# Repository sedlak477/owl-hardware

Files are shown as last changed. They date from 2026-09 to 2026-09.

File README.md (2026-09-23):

# OWL Hardware

Hardware design files for the OWL measurement tool.

<p align="center">
  Exploded 3D render
</p>

The OWL is a rotating platform driven by a BLDC motor under field-oriented control.
Power and USB data are passed from the stationary base to the rotating part through a slip ring,
so devices mounted on top can be rotated continuously while staying connected to a host.

## Status

- **[v1.0.0](https://github.com/sedlak477/owl-hardware/releases/tag/v1.0.0)** is the OWL as built and tested. It works, with the known issues listed in its release notes:
  the 5V rail can oscillate when USB and the power supply are both connected (workaround: cut the controller's `VBUS` jumper JP1),
  the stator's data USB-C port only works in one cable orientation,
  the sensor's mounting holes are missing (drill them, 1.8 mm),
  the green LEDs are very bright,
  and the USB hub (IC1) has no pin-1 marker.
- **Releases after v1.0.0**, including the latest, should fix these issues, but no boards have been built from them yet, so they are **untested**.
  Other changes since the built boards: plated shell-tab holes for the controller's USB-C connector J3, a different part for the controller's `USER` LED D7, and no assembled parts on the controller's bottom side.
- The 5V oscillation is only worked around: JP1 now ships open, so the controller runs from the power supply only (see [Power supply](docs/Assembly%20instructions.md#power-supply)). A proper fix is planned for the next board revision.

## Building an OWL

1. Download the files from the [latest release](https://github.com/sedlak477/owl-hardware/releases/latest):
   - `owl-<version>-jlcpcb.zip`: everything needed to order the three assembled PCBs from JLCPCB
   - `owl-<version>-3d-print.zip`: the 3D-printed parts
   - `owl-<version>-generic.zip`: manufacturer-neutral PCB files and schematics, if you order elsewhere
2. Order the PCBs, see [pcb/README.md](pcb/README.md).
3. Print the parts, see [cad/README.md](cad/README.md).
4. Assemble the OWL and flash the firmware, see the [assembly instructions](docs/Assembly%20instructions.md).
5. Print an adapter for your payload, see [payload/README.md](payload/README.md).

## Architecture

Hardware architecture

- **Stator PCB**: Sits in the stationary base. Provides the USB-C power input with a USB PD trigger (CH224K) and the USB data port to the host.
- **Rotor PCB** (controller): Rotates with the platform. Contains the RP2354B controller, the DRV8311 BLDC driver, 5 V and 3.3 V regulators, a USB hub with a passthrough port for the payload, and a Qwiic (I²C) port.
- **Magnetic sensor PCB**: Measures the rotor angle for motor control using a magnetic angle sensor.

## Repository structure

| Path | Content |
| :--- | :--- |
| `pcb/controller` | KiCad project for the rotor/controller PCB. |
| `pcb/stator` | KiCad project for the stator PCB. |
| `pcb/sensor` | KiCad projects for the magnetic sensor PCBs. |
| `cad` | Link to the Onshape document and 3D-print files.|
| `payload` | Adapters for mounting payloads, and the payload interface. |
| `docs` | Assembly instructions, renders, and diagrams. |

Each PCB folder contains a `schematic.pdf`, the KiCad project in `src`, and production files in `production` (generic, and ready to upload to JLCPCB). See [pcb/README.md](pcb/README.md) for the stackups and how to order the boards.

## Editing the design

Requirements:

- [KiCad](https://www.kicad.org/) 10 or newer
- [Git LFS](https://git-lfs.com/) for STEP models, PDFs, images, and fabrication archives

```sh
git lfs install
git clone git@github.com:sedlak477/owl-hardware.git
```

After changing a board, regenerate its production files with `pcb/export-production.sh` (see [pcb/README.md](pcb/README.md#regenerating-the-production-files-only-after-changing-the-design)).
Pushing a tag starting with `v` (e.g. `v1.1.0`) creates a release with the packaged production and 3D-print files.

## Related resources

[owl-firmware](https://github.com/sedlak477/owl-firmware): The firmware for the OWL platform.  
[owl-ranger](https://github.com/sedlak477/owl-ranger): A script for stepping through some orientations and recording measurements.  
[pyowl](https://github.com/sedlak477/pyowl): A python library for interacting with the OWL.  
[Dataset](https://doi.org/10.3217/kh254-z8374): Orientation-diverse BLE Channel Sounding and UWB ranging measurements recorded with the OWL.

## License

Copyright 2026 Michael Sedlak. Licensed under [CERN-OHL-P-2.0](LICENSE), without any warranty.

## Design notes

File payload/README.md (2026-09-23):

# Payloads

A payload is the device you rotate with the OWL, such as a development board or a set of motion-capture markers.
It sits on an adapter, which locks into the payload connector on top of the OWL (`Rotor - Payload Connector` in [`cad/`](../cad/README.md)).

To attach an adapter, put its pegs through the holes in the payload connector and twist it to lock it in place.
Twist it back to take it off.

> [!CAUTION]
> The pegs are fragile. Don't force the adapter when you twist it.

## Folder structure

| Path | Content |
| :--- | :--- |
| `generic/` | The generic adapter: a blank plate with the pegs, to extend for your own payload. |
| `adapters/<name>/` | Ready-made adapters, each with a STEP model, an image and a README. |
| `mounts/<name>/` | Mounts that provide a payload connector without an OWL. |

## Adapters

| Adapter | For |
| :--- | :--- |
| [`nrf52840dk`](adapters/nrf52840dk/README.md) | Nordic nRF52840 DK |
| [`nrf54l15dk`](adapters/nrf54l15dk/README.md) | Nordic nRF54L15 DK |
| [`dwm3001cdk`](adapters/dwm3001cdk/README.md) | Qorvo DWM3001CDK |
| [`mocap`](adapters/mocap/README.md) | Five optical motion-capture markers |
| [`quarter-inch-thread`](adapters/quarter-inch-thread/README.md) | Anything with a camera tripod screw (female 1/4"-20 thread) |
| [`zip-tie-ring`](adapters/zip-tie-ring/README.md) | Anything you can fix with zip ties or straps |

These adapters were made for our own experiments, and some of them are quick designs that could be done better.
If you improve one, please contribute it back (see [Contributing](#contributing)).

## Using adapters without an OWL

The [tripod mount](mounts/tripod/README.md) screws onto a camera tripod and has the same payload connector as the OWL, so every adapter fits it.
Use it for devices that stay fixed in your setup, such as anchors or reference nodes: they sit on the same adapters and at the same geometry as the rotating ones, and you can move a device between an OWL and a fixed position without taking it off its adapter.

## Electrical interface

The controller PCB on the rotating part offers two connectors for the payload.

### USB-C passthrough

The main connection for a payload.
This port is a downstream port of the controller's USB 2.0 hub, so a payload plugged in there shows up on the host next to the OWL itself, over the same data cable through the slip ring.
It also powers the payload from the controller's 5V rail. With the controller's `VBUS` solder jumper open (as manufactured), that rail runs from the power supply, so the payload is only powered while the power supply is connected.

### Qwiic / STEMMA QT

A JST SH 4-pin connector with the Qwiic / STEMMA QT pinout:

| Pin | Signal | RP2354B |
| :-- | :----- | :--- |
| 1 | GND | |
| 2 | 3.3V | |
| 3 | SDA | GPIO0 |
| 4 | SCL | GPIO1 |

This port connects to the OWL's controller, not to the host, so using it requires changes to the [firmware](https://github.com/sedlak477/owl-firmware).
The controller has no pull-up resistors on SDA and SCL; most Qwiic / STEMMA QT modules have their own.
GPIO0 and GPIO1 can also be configured as UART0 TX and RX, so the port can be used as a UART port instead.

## Designing your own adapter

Start from the generic adapter and build your holder on top of the plate, leaving the pegs unchanged so it still locks into the payload connector.
It is in the [Onshape document](https://cad.onshape.com/documents/fccfa08dfedefe67cfdb683e/w/4726c041ddb97f340fe57a69/e/d62cb220f0c6f90c2b79ed01) with the rest of the OWL, where you can copy it, and in [`generic/payload-generic.step`](generic/payload-generic.step) for any other CAD tool.

## Contributing

New adapters and mounts are welcome, and so are improvements to the existing ones. Add a folder `adapters/<name>/` (or `mounts/<name>/`) with a short lowercase name without spaces, for example the board it holds, containing:

- `<name>.step`: the model
- `<name>.png`: an image of it
- `README.md`: what it holds and any extra hardware needed (screws, inserts, glue)
- optionally `<name>.3mf`, ready to slice

Then add it to the table above and open a pull request.
Contributions are licensed under the same [CERN-OHL-P-2.0](../LICENSE) as the rest of the OWL hardware.

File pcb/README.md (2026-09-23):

# PCBs

| Board | Folder | Layers | Size | Thickness | Copper | Solder mask | Parts on |
| :--- | :--- | :----- | :--- | :--- | :--- | :--- | :--- |
| Rotor / controller | `controller/` | 4 | 60 x 60 mm | 1.6 mm | 1 oz outer, 0.5 oz inner  | Purple | top only |
| Stator | `stator/` | 2 | 44 x 44 mm | 1.6 mm | 1 oz | Black | both sides  |
| Magnetic sensor (MA600A) | `sensor/ma600a/` | 2 | 22.3 x 20 mm | 1.6 mm | 1 oz | Yellow | both sides  |

ENIG surface finish is recommended.
Minimum track width and clearance are 0.15 mm, minimum drill is 0.25 mm (controller) or 0.3 mm (stator, sensor).

Each board folder contains:

| Path | Content |
| :--- | :--- |
| `schematic.pdf` | Schematic. |
| `src/` | KiCad project and STEP model of the assembled board. |
| `production/generic/` | Files for any manufacturer (see below). |
| `production/jlcpcb/`  | Files ready to upload to JLCPCB for fabrication and assembly. |

The easiest way to get the files is the [latest release](https://github.com/sedlak477/owl-hardware/releases/latest): `owl-<version>-jlcpcb.zip` has the JLCPCB files and `owl-<version>-generic.zip` the generic files and schematics, each with one folder per board.

## Ordering from JLCPCB

> [!WARNING]
> **Check the rotation of every part in JLCPCB's placement preview before you order.**
> JLCPCB's part models don't always line up with the footprints, so some parts can show up rotated (often by 90° or 180°) or shifted.
> JLCPCB assembles the board as the preview shows it: a wrongly rotated IC, LED or connector is soldered on the wrong way round, and the board has to be reworked or thrown away.
> See step 5 below.

Order each board (`controller`, `stator`, `sensor-ma600a`) separately. Download and unzip `owl-<version>-jlcpcb.zip`, then for each board:

1. Go to [jlcpcb.com](https://jlcpcb.com), click *Order now*, and upload `<board>/<board>-gerbers.zip`. Don't unzip it, JLCPCB wants the zip.
2. Check that layers, size and thickness match the table above, and pick the solder mask color you like.
3. Enable *PCB Assembly*. The controller is assembled on the top side only; the stator and the sensor have parts on both sides, so select assembly on both sides for them.
4. Upload `<board>/<board>-bom.csv` as the BOM and `<board>/<board>-positions.csv` as the CPL (pick-and-place) file.
5. Check the part matching, then go through **every part** in the placement preview and check both its position and its rotation:
   - Position: its pins sit on their pads.
   - Rotation of ICs: the pin-1 marker on the part (dot, notch or bevel) sits at the pin-1 marker on the silkscreen.
   - Rotation of LEDs: the cathode sits at the cathode marker on the silkscreen.
   - Rotation of connectors: the part matches its silkscreen outline, with the opening on the correct side.

   Rotate or move any part that is off directly in the preview before ordering. Resistors and ceramic capacitors are not polarized, so for them a 180° rotation does not matter.

On the controller, the optional RM2 radio module (U6) and microSD socket (J8) are marked DNP and are not assembled, and neither are their support parts on the bottom side (C43, C44, R1, R2). Solder them by hand if you need them; their values and part numbers are in the schematic.

## Ordering elsewhere

`owl-<version>-generic.zip` (or `production/generic/` in each board folder) contains manufacturer-neutral files, plus each board's schematic:

| File | Content |
| :--- | :--- |
| `<board>-gerbers.zip` | Gerber X2 layers, Excellon drill files (plated and non-plated separate), and a Gerber job file with the stackup. |
| `<board>-netlist.ipc` | IPC-D-356 netlist for electrical testing. |
| `<board>-bom.csv` | BOM with manufacturer and manufacturer part number (MPN), plus the LCSC number where available. |
| `<board>-positions.csv` | Pick-and-place file as exported by KiCad (mm, rotation in KiCad convention, both sides). |

The Gerbers work at any PCB manufacturer.
Assembly houses usually want the BOM and position files in their own format; the columns in the generic files map directly to theirs.
Rotation conventions differ between assembly houses, so **check the rotation of every polarized part in their placement preview**, the same way as for JLCPCB (step 5 above).
The JLCPCB position file is not generic: it contains JLCPCB-specific rotation and offset corrections.

## Regenerating the production files (only after changing the design)

Not needed for ordering boards: the production files in each release are ready to use.

Run `pcb/export-production.sh` (or `pcb/export-production.sh <board>` for one board: `controller`, `stator`, `sensor-ma600a`).
It needs `kicad-cli` (KiCad 10) and, for the JLCPCB files, the [Fabrication Toolkit](https://github.com/bennymeg/Fabrication-Toolkit) KiCad plugin.
Set `KICAD_PYTHON` to the Python interpreter KiCad uses if it is not the default `python3`, and `FABRICATION_TOOLKIT_DIR` if the plugin is not installed in `~/.local/share/kicad/10.0/3rdparty/plugins`.

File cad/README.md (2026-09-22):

# CAD

The mechanical parts of the OWL are designed in Onshape:

<https://cad.onshape.com/documents/fccfa08dfedefe67cfdb683e/w/4726c041ddb97f340fe57a69/e/d62cb220f0c6f90c2b79ed01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>

The Onshape document is the source of truth. Anything in this folder is an export of it.

## Printing the parts

Download `owl-<version>-3d-print.zip` from the [latest release](https://github.com/sedlak477/owl-hardware/releases/latest) and print **`OWL.3mf`**.
It contains all parts for one OWL, already laid out on one plate with a brim, so you only have to open it in your slicer, pick your printer and filament, and print.
Use a heat-resistant filament like ABS or ASA: the motor gets warm, and the motor adapter and the parts around it must not soften.

Alternatively, the archive has one STEP file per part, for example to arrange the parts yourself or to print only the motor adapter in ABS and the rest in another material.

## Files

The same files are in [`3d-print/`](3d-print/):

| File | Content |
| :--- | :--- |
| `OWL.3mf` | All parts for one OWL, laid out on a plate, ready to slice. |
| `Stator - Motor Adapter.step` | Motor adapter. Print in a heat-resistant filament (e.g. ABS). |
| `Stator - Small Spacer.step` | Small spacers between motor adapter and stator PCB. |
| `Stator - Big Spacer.step` | Big spacers between stator PCB and tripod adapter. |
| `Stator - Tripod Adapter.step` | Tripod adapter with the 1/4'' heat insert. |
| `Rotor - Board Spacers.step` | Spacers between sensor PCB and controller PCB. |
| `Rotor - Payload Connector.step` | Payload connector on top of the rotor. |

Each STEP file contains as many copies of the part as one OWL needs.

See the [assembly instructions](../docs/Assembly%20instructions.md) for how the parts go together.

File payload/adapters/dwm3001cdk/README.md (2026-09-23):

# DWM3001CDK adapter

Holds a Qorvo [DWM3001CDK](https://www.qorvo.com/products/p/DWM3001CDK) upright on the OWL. The board snaps into the clips, no screws needed.

DWM3001CDK adapter

| File | Content |
| :--- | :--- |
| `dwm3001cdk.step` | STEP model of the adapter. |

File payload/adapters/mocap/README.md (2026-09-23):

# Motion-capture marker adapter

Carries five optical motion-capture markers on arms of different lengths, so the motion-capture system can track the OWL's rotation as a rigid body.
The arrangement is asymmetric, so every orientation is unambiguous.

Glue the markers onto the round pads at the ends of the arms.

Motion-capture marker adapter

| File | Content |
| :--- | :--- |
| `mocap.step` | STEP model of the adapter. |

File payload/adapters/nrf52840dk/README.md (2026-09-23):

# nRF52840 DK adapter

Holds a Nordic [nRF52840 DK](https://www.nordicsemi.com/Products/Development-hardware/nRF52840-DK) upright on the OWL.

Fix the DK to the plate with M2.5 screws. Nylon screws are recommended.

nRF52840 DK adapter

| File | Content |
| :--- | :--- |
| `nrf52840dk.step` | STEP model of the adapter. |

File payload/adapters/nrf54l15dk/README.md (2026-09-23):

# nRF54L15 DK adapter

Holds a Nordic [nRF54L15 DK](https://www.nordicsemi.com/Products/Development-hardware/nRF54L15-DK) upright on the OWL.

Fix the DK to the plate with M2.5 screws. Nylon screws are recommended.

nRF54L15 DK adapter

| File | Content |
| :--- | :--- |
| `nrf54l15dk.step` | STEP model of the adapter. |

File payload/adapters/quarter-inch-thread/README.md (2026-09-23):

# 1/4" thread adapter

Gives the OWL a female 1/4"-20 UNC thread, the same as on the bottom of a camera.
Anything made for a camera tripod screw can be mounted on it.

To mount a payload that itself has a 1/4" tripod hole, screw a 1/4"-20 male-to-male stud (sold as a "1/4" to 1/4" screw adapter") into this adapter.

It uses the same 1/4" heat insert as the OWL's tripod adapter (see the [assembly instructions](../../../docs/Assembly%20instructions.md)).

1/4 inch thread adapter

| File | Content |
| :--- | :--- |
| `quarter-inch-thread.step` | STEP model of the adapter. |

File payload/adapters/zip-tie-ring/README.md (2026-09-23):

# Zip-tie ring

A plain ring with openings, for fixing payloads that have no dedicated adapter with zip ties, hook-and-loop straps or similar.

Zip-tie ring

| File | Content |
| :--- | :--- |
| `zip-tie-ring.step` | STEP model of the adapter. |

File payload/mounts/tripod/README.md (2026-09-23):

# Tripod mount

Screws onto a camera tripod and provides the same payload connector as the OWL, so any adapter snaps into it just like into an OWL.
Use it for devices that stay fixed in a setup, such as anchors or reference nodes, with the same adapters and mounting geometry as the rotating ones.

It uses the same 1/4" heat insert as the OWL's tripod adapter (see the [assembly instructions](../../../docs/Assembly%20instructions.md)).

Tripod mount

| File | Content |
| :--- | :--- |
| `tripod.step` | STEP model of the mount. |

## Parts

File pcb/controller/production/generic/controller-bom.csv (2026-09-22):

Designator | Quantity | Value | Footprint | Manufacturer | MPN | LCSC
C1,C31,C32,C33 | 4 | 10u 50V | Capacitor_SMD:C_0805_2012Metric | Murata | GRM21BR61H106KE43L | C440198
C2,C14 | 2 | 4.7u | Capacitor_SMD:C_0402_1005Metric | Samsung Electro-Mechanics | CL05A475MP5NRNC | C23733
C3,C10,C11 | 3 | 10u | Capacitor_SMD:C_0603_1608Metric | Samsung Electro-Mechanics | CL10A106KP8NNNC | C19702
C4,C6,C34 | 3 | 100n 50V | Capacitor_SMD:C_0402_1005Metric | Samsung Electro-Mechanics | CL05B104KB54PNC | C307331
C5,C7 | 2 | 4.7u | RP2350_80QFN_minimal:C_0402_1005Metric_small_pads | Samsung Electro-Mechanics | CL05A475MP5NRNC | C23733
C8,C9,C12,C13,C15,C16,C17,C18,C21,C23,C25,C26,C27,C28,C29,C30,C38 | 17 | 100n | Capacitor_SMD:C_0402_1005Metric | Samsung Electro-Mechanics | CL05B104KO5NNNC | C1525
C19,C20 | 2 | 15p | Capacitor_SMD:C_0402_1005Metric | Fenghua | 0402CG150J500NT | C1548
C22,C24 | 2 | 1u | Capacitor_SMD:C_0402_1005Metric | Samsung Electro-Mechanics | CL05A105KA5NQNC | C52923
C35,C36,C37 | 3 | 22u | Capacitor_SMD:C_0603_1608Metric | Fenghua | 0603X226M100NT | C60077
C39,C40 | 2 | 18p | Capacitor_SMD:C_0402_1005Metric | Fenghua | 0402CG180J500NT | C1549
C42 | 1 | 100n 50V | Capacitor_SMD:C_0402_1005Metric | Murata | GRM155R71H104KE14D | C77020
D2,D8,D9 | 3 | KT-0805G | LED_SMD:LED_0805_2012Metric | Hubei KENTO Elec | KT-0805G | C2297
D4 | 1 | KT-0805Y | LED_SMD:LED_0805_2012Metric | Hubei KENTO Elec | KT-0805Y | C2296
D5,D6 | 2 | KT-0805R | LED_SMD:LED_0805_2012Metric | NATIONSTAR | NCD0805R1 | C84256
D7 | 1 | KT-0805B | LED_SMD:LED_0805_2012Metric | Hubei KENTO Elec | KT-0805B | C2293
IC1 | 1 | USB2422-I_MJ | USB2422-I_MJ:QFN50P400X400X100-25N | Microchip | USB2422-I/MJ | C220747
J1 | 1 | Motor | Connector_Molex:Molex_PicoBlade_53261-0371_1x03-1MP_P1.25mm_Horizontal | Molex | 532610371 | C293630
J3 | 1 | USB_C_Receptacle_USB2.0_14P | Connector_USB:USB_C_Receptacle_GCT_USB4105-xx-A_16P_TopMnt_Horizontal | Global Connector Technology | USB4105-GF-A-060 | C3025063
J4 | 1 | Slip Ring | JST PA 6P:CONN_BM06B-PASS-1_JST | JST | BM06B-PASS-TFT(LF)(SN) | C265376
J5 | 1 | 781715006 | Molex Pico-EZmate 781715006:CONN06_781715006_MOL | Molex | 781715006 | C107412
J6 | 1 | SM03B-SRSS-TB | Connector_JST:JST_SH_SM03B-SRSS-TB_1x03-1MP_P1.00mm_Horizontal | JST | SM03B-SRSS-TB(LF)(SN) | C160403
J9 | 1 | SM04B-SRSS-TB_LF__SN_ | SM04B-SRSS-TB:JST_SM04B-SRSS-TB_LF__SN_ | JST | SM04B-SRSS-TB(LF)(SN) | C160404
L1 | 1 | 3.3u | AOTA-B201610S3R3-101-T:AOTAB201610S3R3101T | Abracon | AOTA-B201610S3R3-101-T | C42411119
PS1 | 1 | TPSM84338RCJR | TPSM84338RCJR:CONV_TPSM84338RCJR | Texas Instruments | TPSM84338RCJR | C47122151
R3,R6 | 2 | 1.43k | Resistor_SMD:R_0402_1005Metric | Yageo | RC0402FR-071K43L | C163483
R4 | 1 | 10k | Resistor_SMD:R_0402_1005Metric | UNI-ROYAL | 0402WGF1002TCE | C25744
R5,R22,R23,R24,R26 | 5 | 47k | Resistor_SMD:R_0402_1005Metric | UNI-ROYAL | 0402WGF4702TCE | C25792
R11 | 1 | 270 | Resistor_SMD:R_0402_1005Metric | Yageo | RC0402FR-07270RL | C163474
R13 | 1 | 33 | Resistor_SMD:R_0402_1005Metric | UNI-ROYAL | 0402WGF330JTCE | C25105
R14,R15,R18,R34,R36,R41 | 6 | 1k | Resistor_SMD:R_0402_1005Metric | UNI-ROYAL | 0402WGF1001TCE | C11702
R16,R17 | 2 | 27 | Resistor_SMD:R_0402_1005Metric | Yageo | RC0402FR-0727RL | C138021
R19,R20 | 2 | 100k | Resistor_SMD:R_0402_1005Metric | UNI-ROYAL | 0402WGF1003TCE | C25741
R21 | 1 | 12k | Resistor_SMD:R_0402_1005Metric | UNI-ROYAL | 0402WGF1202TCE | C25752
R25,R27 | 2 | 22k | Resistor_SMD:R_0402_1005Metric | UNI-ROYAL | 0402WGF2202TCE | C25768
R28 | 1 | 330 | Resistor_SMD:R_0402_1005Metric | UNI-ROYAL | 0402WGF3300TCE | C25104
R29 | 1 | 110k | Resistor_SMD:R_0402_1005Metric | Yageo | RC0402FR-07110KL | C138065
R30 | 1 | 15k | Resistor_SMD:R_0402_1005Metric | UNI-ROYAL | 0402WGF1502TCE | C25756
R31 | 1 | 0 | Resistor_SMD:R_0402_1005Metric | UNI-ROYAL | 0402WGF0000TCE | C17168
R32 | 1 | 18k | Resistor_SMD:R_0402_1005Metric | UNI-ROYAL | 0402WGF1802TCE | C25762
R38,R40 | 2 | 360 | Resistor_SMD:R_0402_1005Metric | FOJAN | FRC0402F3600TS | C2930003
R39 | 1 | 4.7k | Resistor_SMD:R_0402_1005Metric | UNI-ROYAL | 0402WGF4701TCE | C25900
SW1 | 1 | BOOTSEL | Button_Switch_SMD:SW_SPST_B3U-1000P | G-Switch | GT-TC032A-H015-L1 | C843684
SW2 | 1 | RESET | Button_Switch_SMD:SW_SPST_B3U-1000P | G-Switch | GT-TC032A-H015-L1 | C843684
SW3 | 1 | USER | Button_Switch_SMD:SW_SPST_B3U-1000P | G-Switch | GT-TC032A-H015-L1 | C843684
U1 | 1 | AP2112K-3.3 | Package_TO_SOT_SMD:SOT-23-5 | TECH PUBLIC | AP2112K-3.3TRG1 | C23380830
U2 | 1 | LM66200DRLR | LM66200DRLR:SOT-5X3_DRL_TEX | Texas Instruments | LM66200DRLR | C3235556
U3 | 1 | PDRV8311HRRWR | DRV8311:RRW0024-MFG | Texas Instruments | DRV8311HRRWR | C5218862
U4 | 1 | RP2354B | Package_DFN_QFN:QFN-80-1EP_10x10mm_P0.4mm_EP3.4x3.4mm_ThermalVias | Raspberry Pi | RP2354B | C39843328
U5 | 1 | USBLC6-2P6 | Package_TO_SOT_SMD:SOT-666 | TECH PUBLIC | USBLC6-2P6 | C2827693
Y1 | 1 | ABM8-272-T3 | ABM8-272-T3:XTAL_ABM8-272-T3 | Abracon | ABM8-272-T3 | C20625731
Y2 | 1 | 7M-24.000MAAJ-T | 7M-24.000MAAJ-T:7M24000MAAJT | TXC | 7M-24.000MAAJ-T | C2450233

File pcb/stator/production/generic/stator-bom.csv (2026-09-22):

Designator | Quantity | Value | Footprint | Manufacturer | MPN | LCSC
C1,C4 | 2 | 100n | Capacitor_SMD:C_0402_1005Metric | Fenghua | 0402F104M500NT | C1581
C3 | 1 | 1u | Capacitor_SMD:C_0402_1005Metric | Samsung Electro-Mechanics | CL05A105KA5NQNC | C52923
J1 | 1 | DATA | Connector_USB:USB_C_Receptacle_GCT_USB4110 | Global Connector Technology | USB4110-GF-A | C5143397
J2 | 1 | SLIP RING | JST PA 6P SMT:CONN_BM06B-PASS-1_JST | JST | BM06B-PASS-TFT(LF)(SN) | C265376
J3 | 1 | POWER | Connector_USB:USB_C_Receptacle_GCT_USB4110 | Global Connector Technology | USB4110-GF-A | C5143397
R1,R6 | 2 | 330 | Resistor_SMD:R_0402_1005Metric | UNI-ROYAL | 0402WGF3300TCE | C25104
R2,R3 | 2 | 5.1k | Resistor_SMD:R_0402_1005Metric | UNI-ROYAL | 0402WGF5101TCE | C25905
R4,R7,R8,R9 | 4 | 10k | Resistor_SMD:R_0402_1005Metric | UNI-ROYAL | 0402WGF1002TCE | C25744
R5 | 1 | 1k | Resistor_SMD:R_0805_2012Metric | UNI-ROYAL | AS05W2J0102T5E | C560481
U2 | 1 | CH224K | Package_SO:SSOP-10-1EP_3.9x4.9mm_P1mm_EP2.1x3.3mm | WCH | CH224K | C970725

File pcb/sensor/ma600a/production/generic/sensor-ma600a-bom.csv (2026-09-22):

Designator | Quantity | Value | Footprint | Manufacturer | MPN | LCSC
C1 | 1 | 100n | Capacitor_SMD:C_0603_1608Metric | Yageo | CC0603KRX7R9BB104 | C14663
C2 | 1 | 1u | Capacitor_SMD:C_0603_1608Metric | Samsung Electro-Mechanics | CL10A105KB8NNNC | C15849
J1 | 1 | 781715006 | Molex Pico-EZmate 781715006:CONN06_781715006_MOL | Molex | 781715006 | C107412
U2 | 1 | MA600A | Package_DFN_QFN:QFN-16-1EP_3x3mm_P0.5mm_EP1.75x1.75mm | Monolithic Power Systems | MA600AGQE-0000-Z | C49240579

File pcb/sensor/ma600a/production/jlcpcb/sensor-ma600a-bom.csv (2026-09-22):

Designator | Footprint | Quantity | Value | LCSC Part #
C1 | 0603 | 1 | 100n | C14663
C2 | 0603 | 1 | 1u | C15849
J1 | CONN06_781715006_MOL | 1 | 781715006 | C107412
U2 | QFN-16-1EP_3x3mm_P0.5mm_EP1.75x1.75mm | 1 | MA600A | C49240579

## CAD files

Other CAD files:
cad/3d-print/OWL.3mf
payload/adapters/dwm3001cdk/dwm3001cdk.step
payload/adapters/mocap/mocap.step
payload/adapters/nrf54l15dk/nrf54l15dk.step
payload/adapters/quarter-inch-thread/quarter-inch-thread.step
payload/adapters/zip-tie-ring/zip-tie-ring.step
payload/generic/payload-generic.step
payload/mounts/tripod/tripod.step
pcb/controller/src/OWL - Rotor v2.step
pcb/sensor/ma600a/src/Sensor - MA600A.step
pcb/stator/src/Stator.step
cad/3d-print/Rotor - Payload Connector.step
cad/3d-print/Rotor - Board Spacers.step
cad/3d-print/Stator - Small Spacer.step
cad/3d-print/Stator - Big Spacer.step
cad/3d-print/Stator - Motor Adapter.step
cad/3d-print/Stator - Tripod Adapter.step
payload/adapters/nrf52840dk/nrf52840dk.step

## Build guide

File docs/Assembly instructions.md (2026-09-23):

1. 3D-print all parts & cleanup from print (especially the payload connector mounting holes). Download `owl-<version>-3d-print.zip` from the [latest release](https://github.com/sedlak477/owl-hardware/releases/latest) and print `OWL.3mf`: it has all parts for one OWL laid out on one plate, ready to slice. Print it in a heat-resistant filament like ABS or ASA, because the motor gets warm and the motor adapter and the parts around it must not soften. If you want to arrange the parts yourself, or print only some of them in another material, use the STEP files in the same archive instead (see [`cad/`](../cad/README.md)).
2. Prepare materials
	1. 1x BLDC motor: SparkFun [ROB-20441](https://www.sparkfun.com/three-phase-brushless-gimbal-stabilizer-motor.html) (Mouser 474-ROB-20441)
	2. 1x slip ring, 6 wire, 2A: SparkFun [ROB-13064](https://www.sparkfun.com/slip-ring-6-wire-2a.html) (Mouser 474-ROB-13064)
	3. 1x stator PCB, 1x controller PCB, 1x sensor PCB, ordered assembled from JLCPCB with the files in `owl-<version>-jlcpcb.zip` from the [latest release](https://github.com/sedlak477/owl-hardware/releases/latest); see [how to order the boards](../pcb/README.md)
	4. 3x M5 nuts
	5. 3x M5 counter-sunk screws, 40mm long
	6. 3x M1.6x6 flat-head screws
	7. 3x M1.6x10 flat-head screws
	8. 1x 1/4'' heat insert, 8.7mm outer diameter, ~12.7mm long (a shorter one works too, it just must not be longer)
	9. 1x Molex Pico-EZmate cable assembly, 6 circuits, 50mm: [36920-0600](https://www.molex.com/en-us/products/part-detail/369200600) (Mouser 538-36920-0600)
	10. 2x JST PA 6-pin housing (PAP-06V-S) with 12x crimp contacts, for the slip ring
	11. 2x USB-C cables. Take care with cheap cables: many are charge-only and have no data lines.
	12. 1x USB-C power supply that can deliver the voltage the stator requests (see below)
3. Tools: soldering iron (for the heat insert), crimping tool for JST PA contacts, wire strippers, side cutters, 2mm allen key, multimeter
4. Break the PCBs out of their panels, if they came panelized: snap or cut off the panel rails and file the leftover breakaway tabs flush.
5. Press the 1/4'' heat insert into the tripod adapter
	1. Insert until 1mm still sticks out
	2. While still hot, turn around and press against flat surface (CAUTION: Don't press on the center with your finger or you could burn yourself on the heat insert)
	3. This ensures the insert is level with the bottom surface
6. Put the M5 bolts into the motor adapter
7. Mount the motor to the top of the motor adapter
	1. Pre-screw the M1.6x6 screws into the small holes; Leave 1/2mm sticking out of the top to make aligning the motor easier
	2. Ensure the M5 bolts are already inserted into the big holes
	3. Align the motor (magnetic ring facing away) with the screws and tighten the screws
	4. Ensure the motor does not wiggle and it rotates freely. If it sounds like it is scraping, then the screws are going in too far and are damaging the motors internals!

	Motor mounted on the motor adapter with the three M5 bolts inserted

8. Thread the cables of the slip ring through the motor and slide it onto the M5 screws. The thin side of the slip ring should disappear into the motor adapter and the flange should sit flush against the motor adapter.

	Slip ring cables being threaded through the motor and motor adapter

9. Add one small spacer to each M5 screw, then slide on the stator PCB with the connectors facing *away* from the assembly. Ensure you thread the slip ring cables through the large center hole of the stator PCB and the connectors are aligned with the symbols (the JST connector should be on the side where there's no symbol)

	Stator PCB slid onto the M5 bolts over the small spacers, slip ring cables through the center hole

10. Cut the cables to size (leave some slack to allow for some mistakes when crimping), strip the ends, and crimp on the JST crimps.
11. Insert the crimps into the connector housing, remember the order (or better, take a picture). The order does not matter, but it just has to match the order on the other side. I recommend ordering them so the cables can lie pretty coming out of the connector.

	Crimped slip ring wires in the JST PA housing, in the order yellow, red, black, green, orange, brown

	Slip ring wires crimped and inserted into the housing, plugged into the stator PCB

12. Insert the connector
13. Slide two big spacers onto each M5 screw, carefully bend the cables to the side, and slide on the tripod adapter.

	Big spacers on the M5 bolts with the slip ring cables bent to the side

14. Screw the M5 nuts onto the ends of the M5 screws. Depending on 3D printing tolerances, an allen key should just fit beside the motor to turn the screw. After a few rotations, the nut will be held in place by the tripod adapter and you can tighten it all the way.

	Finished stator assembly with the tripod adapter, M5 nuts and heat insert

15. The stator assembly is now finished!
16. Thread the slip ring and motor cables through the center hole of the controller PCB and place it on top of the motor.

	Controller PCB placed on top of the motor with the slip ring and motor cables through its center hole

17. Again, cut the wires to length and crimp on the connector (same as steps 10 & 11). Ensure you insert the cables in the same order as on the other end.
18. Before plugging anything in, check the slip ring wiring with a multimeter. Unplug the housing on the stator side and measure continuity between the two housings: pin 1 must reach pin 1, pin 2 must reach pin 2, and so on. If the crimps went in mirrored, the order still "matches" but VM ends up on VBUS. Also check that no two neighbouring pins are shorted by a crimp.
19. Plug in the slip ring connector and the motor connector.
20. !!!!! Make sure the slip ring cables are bent to the side and lay flat against the PCB, so the sensor can later be mounted on top.
21. Plug the Pico-EZmate cable into the sensor PCB. Lay the sensor flat on the table, align the connector from the top and just press down, the connector should click into place very easily.
22. Thread the M1.6x10 screws through the payload connector, slide on the sensor PCB (the sensor IC facing *away* from the payload connector), and slide on the board spacers. The fit on the spacers is tight, so I recommend screwing into them and letting 2mm stick out for alignment.

	Payload connector with the sensor PCB and board spacers, side view Payload connector with the sensor PCB and board spacers, top view

23. Align the controller PCB with the motor's mounting holes, add the payload connector + sensor assembly on top, and screw the three M1.6 screws down into the motor.
24. Plug the other end of the Pico-EZmate cable into the controller PCB.

## Power supply

The stator uses a CH224K USB PD trigger to ask the power supply for the motor voltage.
Which voltage it requests is set by the solder jumpers JP1 (CFG1), JP2 (CFG2) and JP3 (CFG3) on the stator PCB.
As manufactured, the stator requests 9V.
Any USB-C PD supply that offers 9V will do.

You can change the requested voltage with the jumpers.
If you do, also set `SUPPLY_VOLTAGE` in the firmware's [`src/main.cpp`](https://github.com/sedlak477/owl-firmware/blob/main/src/main.cpp) to the new voltage, otherwise SimpleFOC computes the wrong phase voltages.
The firmware limits the motor to 4V (`motor.voltage_limit`); keep it below the motor's 7.4V rating.

The controller's 5V rail comes from its regulator, which runs from the motor supply.
It can also be powered from USB through the `VBUS` solder jumper JP1 on the controller PCB, which is open as manufactured.
Bridge JP1 only if the controller should also run from USB power alone: with both power and data connected, the controller's power path can then keep switching between the two sources and make the 5V rail noisy.

## Checks

You are now done with the mechanical assembly! A few checks before continuing:
- Make sure the top rotates freely
- Check the following LEDs
	- Power plugged in, data **unplugged**
		- `VM`: green
		- `5V`: green
		- `3.3V`: green
		- Rest off (`USB`, `USER`, `DRV FAULT`, `PG`)
	- Power **unplugged**, data plugged in
		- All off, since the controller only runs from the power supply (JP1 open)
		- If you bridged JP1: `5V` green, `3.3V` green, `USB` yellow, rest off (`VM`, `USER`, `DRV FAULT`, `PG`)
	- Both plugged in
		- `VM`: green
		- `5V`: green
		- `3.3V`: green
		- `USB`: yellow
		- Rest off  (`USER`, `DRV FAULT`, `PG`)

If those checks passed, you can continue on to flashing the firmware.

## Flashing the firmware

1. Download the latest `.uf2` image from the [owl-firmware releases](https://github.com/sedlak477/owl-firmware/releases) page.
2. Plug in the data cable and the power cable. On a new board the flash is blank, so the controller starts in BOOT mode by itself.
3. To reflash a board that already has firmware, put it into BOOT mode: hold the BOOT button, press and release RESET, then release BOOT. Holding BOOT while plugging in the power cable works too.
4. The OWL will show up as a USB thumb drive.
5. Copy the firmware image to this drive.
6. The controller will flash the firmware and reset.
7. Done!

## First power-up and the 0° position

Every time the controller starts (power-up, reset, or right after flashing), the firmware:

1. Calibrates the motor against the sensor: the top twitches briefly back and forth.
2. Slowly turns the top to its 0° position. This can take up to almost one full revolution.

Keep the top free to rotate while this happens: if it is blocked, the calibration fails.
You can tell the two cases apart by hand:

- **Calibrated:** the top resists when you push it and always returns to its set point.
- **Calibration failed:** the motor is switched off and the top turns freely by hand. Power-cycle the OWL to try again.

The 0° position comes from the magnetic sensor, so it is the same physical orientation every time the OWL starts, as long as it is not taken apart.
It is not tied to any mark on the OWL and differs from one OWL to the next.
To get a known orientation in your test setup, power the OWL up, wait until it has turned to 0°, and then turn the whole OWL (for example on its tripod) until the payload faces your reference direction.
Pressing the `USER` button also sends the OWL back to 0° (one second after you release it).

The controller and sensor PCBs both have a `0°` silkscreen mark. You don't need to line them up: the firmware does not use them. Defining a mechanical zero with these marks is future work.

## What next

To mount your device on the OWL, print an adapter for it, see [`payload/`](../payload/README.md).
For a first controlled move, use [pyowl](https://github.com/sedlak477/pyowl), the Python library for the OWL.
To step through orientations and record measurements, use [owl-ranger](https://github.com/sedlak477/owl-ranger).

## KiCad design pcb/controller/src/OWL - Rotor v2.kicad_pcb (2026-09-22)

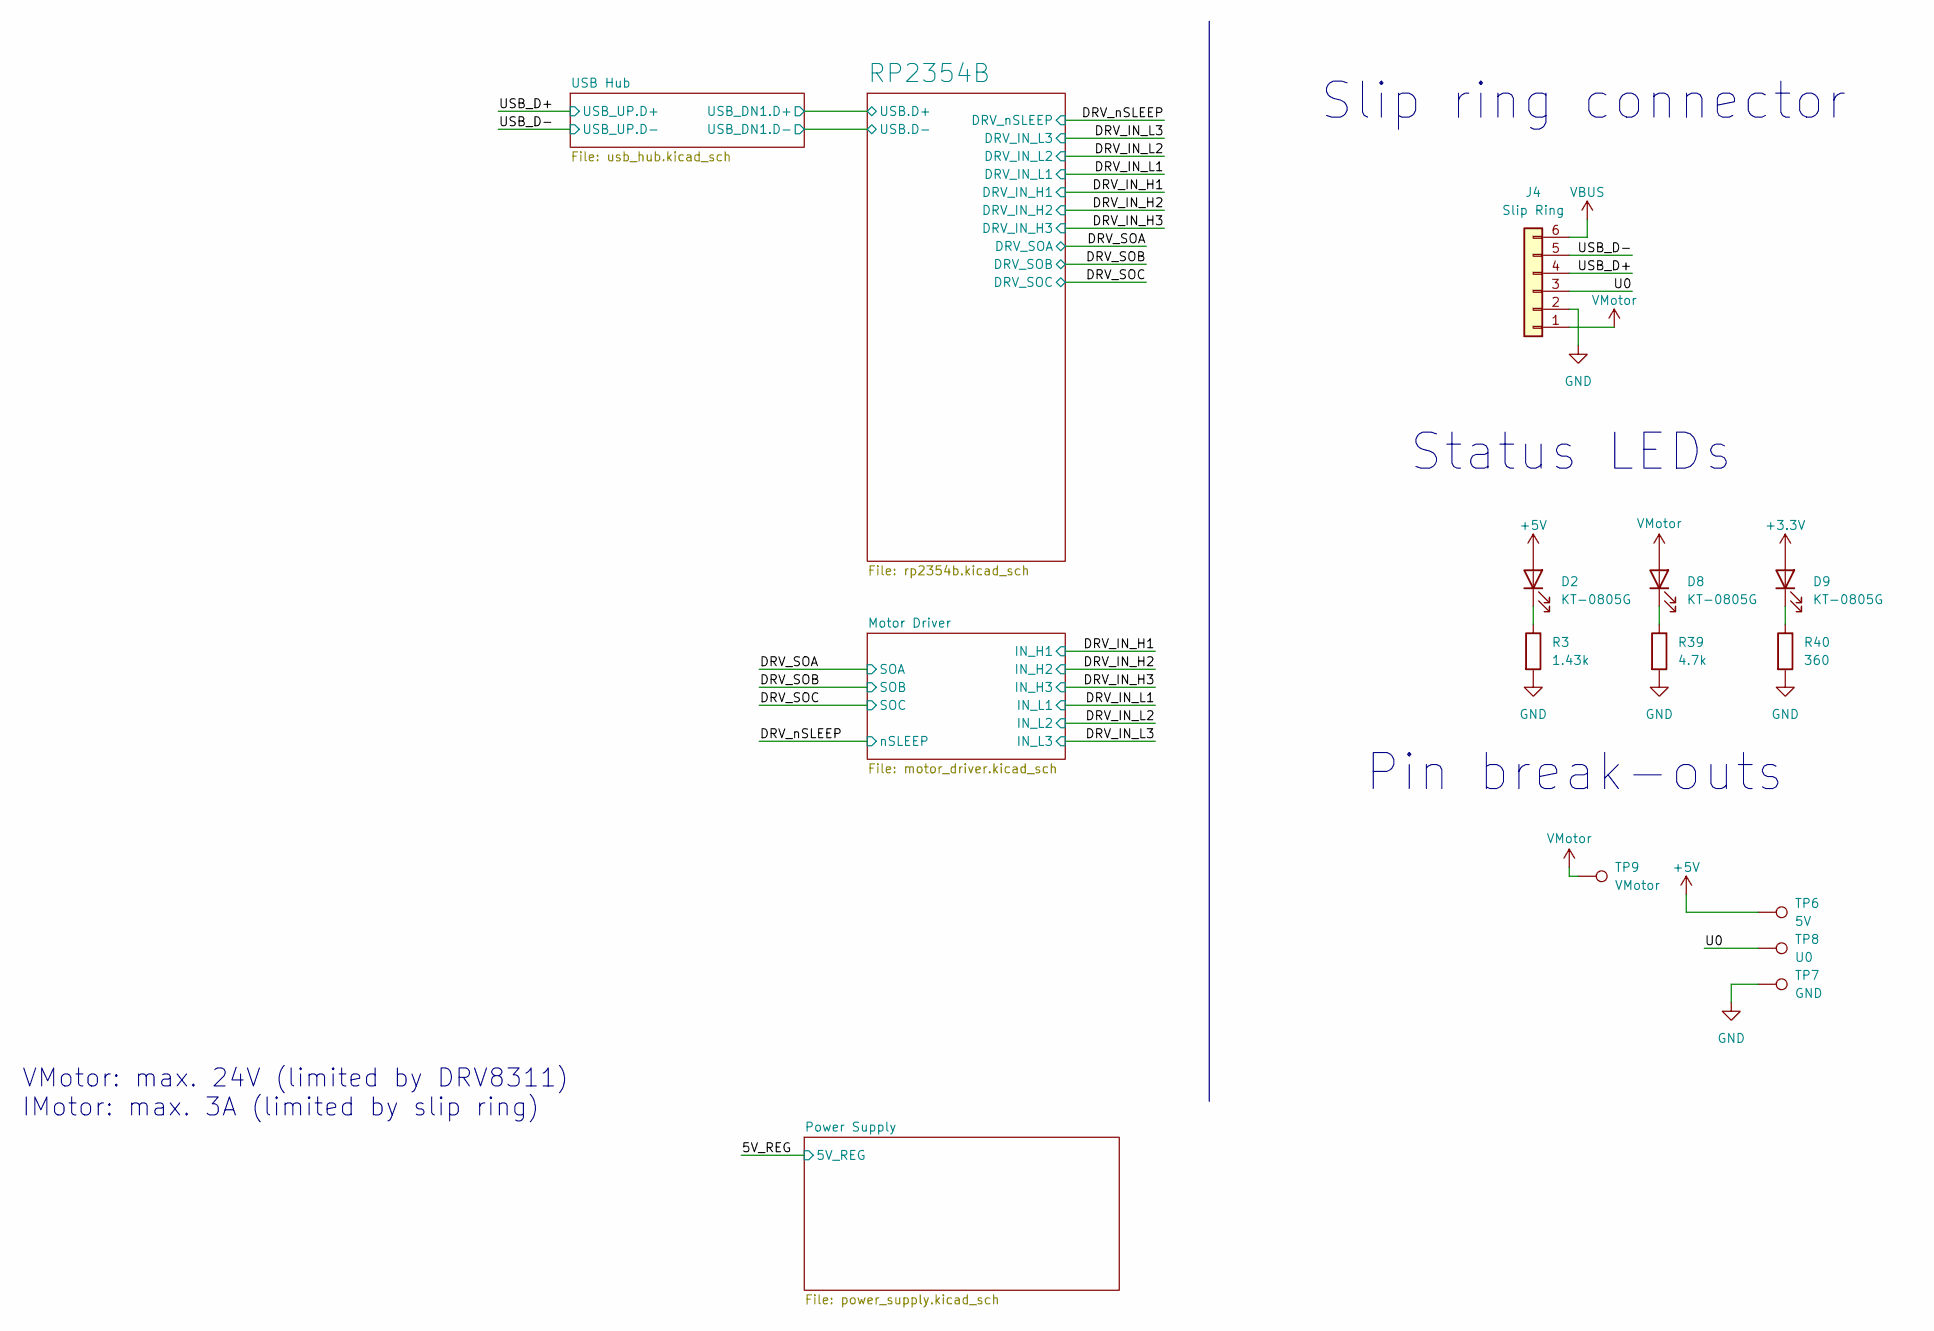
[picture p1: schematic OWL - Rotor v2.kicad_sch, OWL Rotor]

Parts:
D2, D8, D9: KT-0805G; LED_0805_2012Metric; MPN KT-0805G; LCSC C2297
J4: Slip Ring; CONN_BM06B-PASS-1_JST; MPN BM06B-PASS-TFT(LF)(SN); LCSC C265376
R3: 1.43k; R_0402_1005Metric; MPN RC0402FR-071K43L; LCSC C163483
R39: 4.7k; R_0402_1005Metric; MPN 0402WGF4701TCE; LCSC C25900
R40: 360; R_0402_1005Metric; MPN FRC0402F3600TS; LCSC C2930003
TP6: 5V; TestPoint_Pad_D1.0mm
TP7: GND; TestPoint_Pad_D1.0mm
TP8: U0; TestPoint_Pad_D1.0mm
TP9: VMotor; TestPoint_Pad_D1.0mm

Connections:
+3.3V: D9.2 (A); also elsewhere on the board
+5V: D2.2 (A), TP6.1; also elsewhere on the board
/U0: J4.3, TP8.1
/USB_D+: J4.4; also elsewhere on the board
/USB_D-: J4.5; also elsewhere on the board
GND: J4.2, R3.2, R39.2, R40.2, TP7.1; also elsewhere on the board
unnamed: D2.1 (K), R3.1
unnamed: D8.1 (K), R39.1
unnamed: D9.1 (K), R40.1
VBUS: J4.6; also elsewhere on the board
VMotor: D8.2 (A), J4.1, TP9.1; also elsewhere on the board

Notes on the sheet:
VMotor: max. 24V (limited by DRV8311) IMotor: max. 3A (limited by slip ring)
Status LEDs
Slip ring connector
Pin break-outs

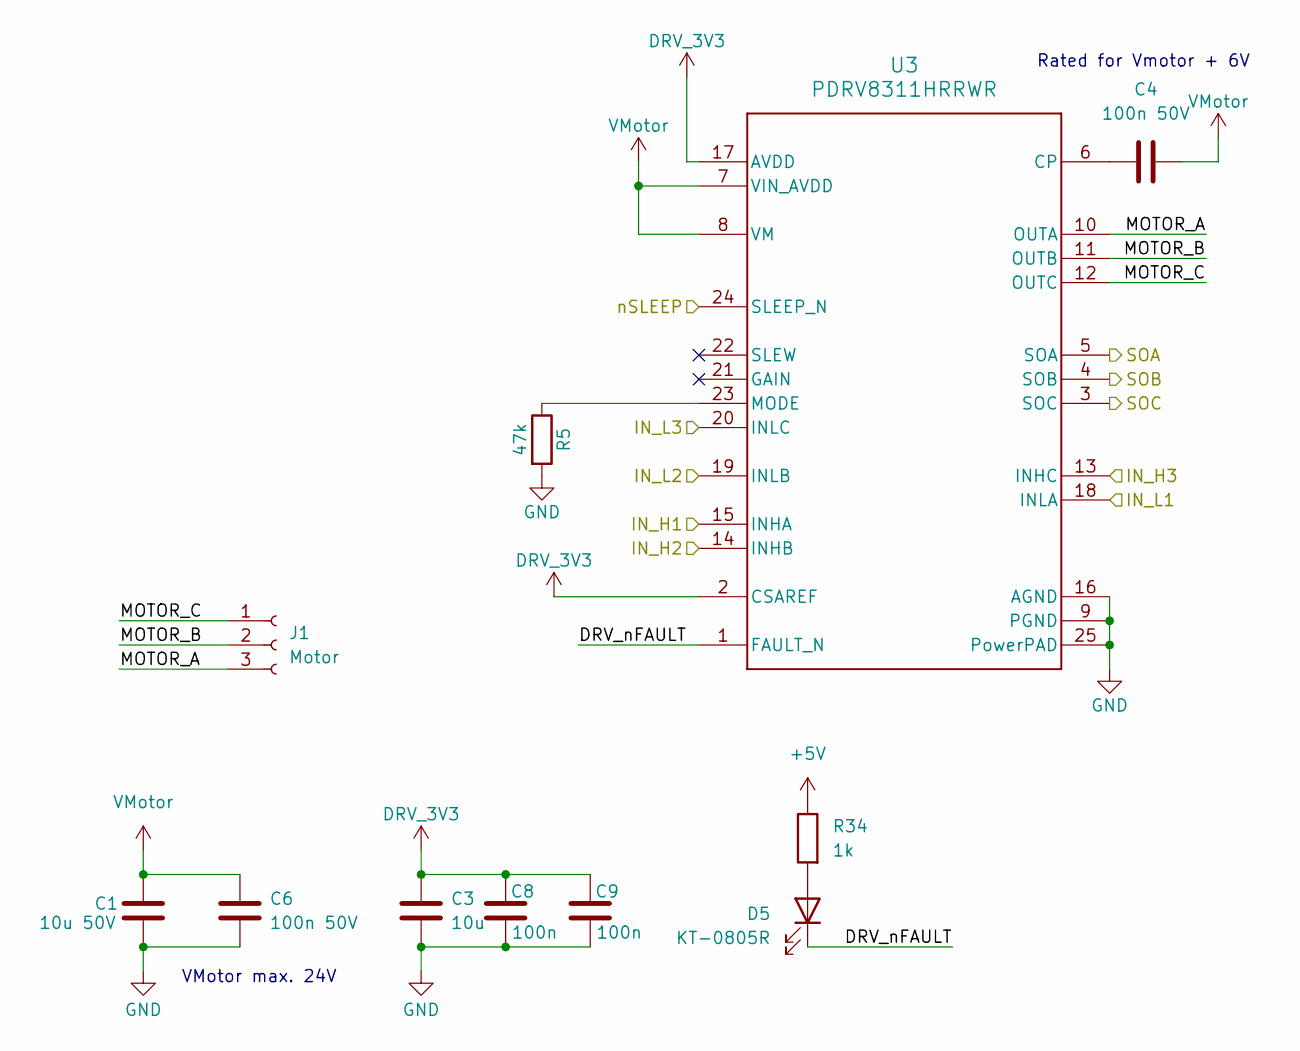
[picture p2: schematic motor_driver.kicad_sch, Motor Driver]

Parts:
C1: 10u 50V; C_0805_2012Metric; MPN GRM21BR61H106KE43L; LCSC C440198
C3: 10u; C_0603_1608Metric; MPN CL10A106KP8NNNC; LCSC C19702
C4, C6: 100n 50V; C_0402_1005Metric; MPN CL05B104KB54PNC; LCSC C307331
C8, C9: 100n; C_0402_1005Metric; MPN CL05B104KO5NNNC; LCSC C1525
D5: KT-0805R; LED_0805_2012Metric; MPN NCD0805R1; LCSC C84256
J1: Motor; Molex_PicoBlade_53261-0371_1x03-1MP_P1.25mm_Horizontal; MPN 532610371; LCSC C293630
R5: 47k; R_0402_1005Metric; MPN 0402WGF4702TCE; LCSC C25792
R34: 1k; R_0402_1005Metric; MPN 0402WGF1001TCE; LCSC C11702
U3: PDRV8311HRRWR; RRW0024-MFG; MPN DRV8311HRRWR; LCSC C5218862

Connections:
+5V: R34.1; also elsewhere on the board
/DRV_IN_H1: U3.15 (INHA); also elsewhere on the board
/DRV_IN_H2: U3.14 (INHB); also elsewhere on the board
/DRV_IN_H3: U3.13 (INHC); also elsewhere on the board
/DRV_IN_L1: U3.18 (INLA); also elsewhere on the board
/DRV_IN_L2: U3.19 (INLB); also elsewhere on the board
/DRV_IN_L3: U3.20 (INLC); also elsewhere on the board
/DRV_SOA: U3.5 (SOA); also elsewhere on the board
/DRV_SOB: U3.4 (SOB); also elsewhere on the board
/DRV_SOC: U3.3 (SOC); also elsewhere on the board
/DRV_nSLEEP: U3.24 (SLEEP_N); also elsewhere on the board
/Motor Driver/DRV_nFAULT: D5.1 (K), U3.1 (FAULT_N)
/Motor Driver/MOTOR_A: J1.3, U3.10 (OUTA)
/Motor Driver/MOTOR_B: J1.2, U3.11 (OUTB)
/Motor Driver/MOTOR_C: J1.1, U3.12 (OUTC)
DRV_3V3: C3.1, C8.2, C9.2, U3.2 (CSAREF), U3.17 (AVDD)
GND: C1.2, C3.2, C6.2, C8.1, C9.1, R5.2, U3.9 (PGND), U3.16 (AGND), U3.25 (PowerPAD); also elsewhere on the board
unnamed: D5.2 (A), R34.2
unnamed: C4.1, U3.6 (CP)
unnamed: R5.1, U3.23 (MODE)
VMotor: C1.1, C4.2, C6.1, U3.7 (VIN_AVDD), U3.8 (VM); also elsewhere on the board

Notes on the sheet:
Rated for Vmotor + 6V
VMotor max. 24V

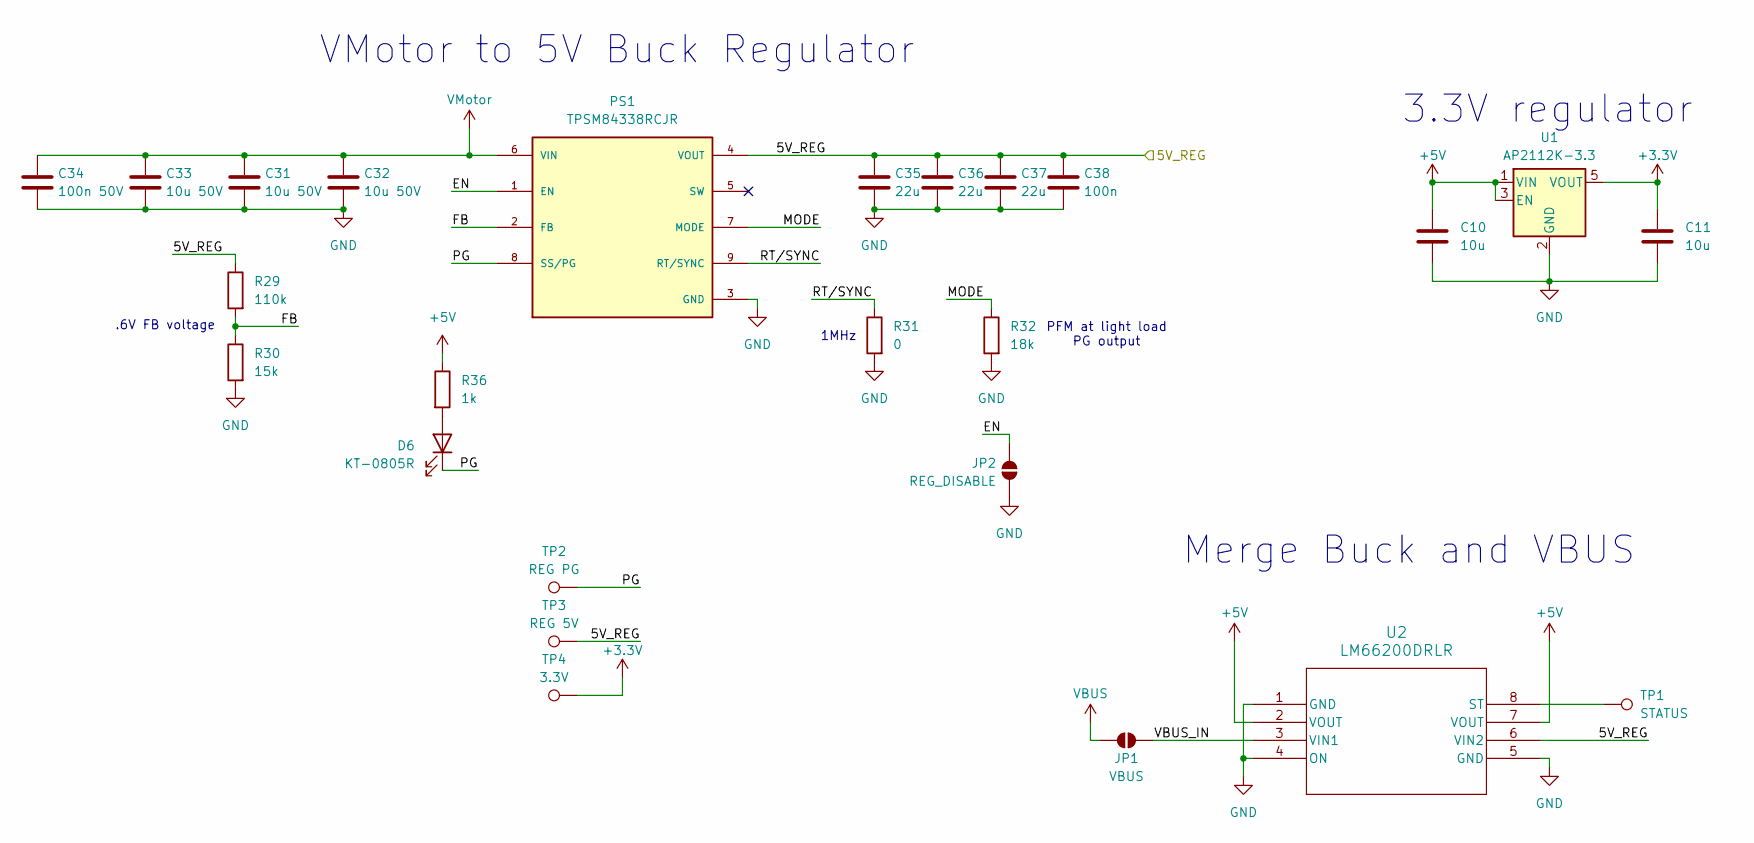
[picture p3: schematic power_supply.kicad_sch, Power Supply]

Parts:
C10, C11: 10u; C_0603_1608Metric; MPN CL10A106KP8NNNC; LCSC C19702
C31, C32, C33: 10u 50V; C_0805_2012Metric; MPN GRM21BR61H106KE43L; LCSC C440198
C34: 100n 50V; C_0402_1005Metric; MPN CL05B104KB54PNC; LCSC C307331
C35, C36, C37: 22u; C_0603_1608Metric; MPN 0603X226M100NT; LCSC C60077
C38: 100n; C_0402_1005Metric; MPN CL05B104KO5NNNC; LCSC C1525
D6: KT-0805R; LED_0805_2012Metric; MPN NCD0805R1; LCSC C84256
JP1: VBUS; SolderJumper-2_P1.3mm_Open_RoundedPad1.0x1.5mm
JP2: REG_DISABLE; SolderJumper-2_P1.3mm_Open_RoundedPad1.0x1.5mm
PS1: TPSM84338RCJR; CONV_TPSM84338RCJR; PARTREV November 2024; LCSC C47122151
R29: 110k; R_0402_1005Metric; MPN RC0402FR-07110KL; LCSC C138065
R30: 15k; R_0402_1005Metric; MPN 0402WGF1502TCE; LCSC C25756
R31: 0; R_0402_1005Metric; MPN 0402WGF0000TCE; LCSC C17168
R32: 18k; R_0402_1005Metric; MPN 0402WGF1802TCE; LCSC C25762
R36: 1k; R_0402_1005Metric; MPN 0402WGF1001TCE; LCSC C11702
TP1: STATUS; TestPoint_Pad_D1.0mm
TP2: REG PG; TestPoint_Pad_D1.0mm
TP3: REG 5V; TestPoint_Pad_D1.0mm
TP4: 3.3V; TestPoint_Pad_D1.0mm
U1: AP2112K-3.3; SOT-23-5; MPN AP2112K-3.3TRG1; LCSC C23380830
U2: LM66200DRLR; SOT-5X3_DRL_TEX; MPN LM66200DRLR; LCSC C3235556

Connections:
+3.3V: C11.1, TP4.1, U1.5 (VOUT); also elsewhere on the board
+5V: C10.1, R36.1, U1.1 (VIN), U1.3 (EN), U2.2 (VOUT), U2.7 (VOUT); also elsewhere on the board
/5V_REG: C35.1, C36.1, C37.1, C38.1, PS1.4 (VOUT), R29.1, TP3.1, U2.6 (VIN2)
/Power Supply/EN: JP2.2 (B), PS1.1 (EN)
/Power Supply/FB: PS1.2 (FB), R29.2, R30.1
/Power Supply/MODE: PS1.7 (MODE), R32.1
/Power Supply/PG: D6.1 (K), PS1.8 (SS/PG), TP2.1
/Power Supply/RT/SYNC: PS1.9 (RT/SYNC), R31.1
/Power Supply/VBUS_IN: JP1.1 (A), U2.3 (VIN1)
GND: C10.2, C11.2, C31.2, C32.2, C33.2, C34.2, C35.2, C36.2, C37.2, C38.2, JP2.1 (A), PS1.3 (GND), R30.2, R31.2, R32.2, U1.2 (GND), U2.1 (GND), U2.4 (ON), U2.5 (GND); also elsewhere on the board
unnamed: D6.2 (A), R36.2
unnamed: TP1.1, U2.8 (ST)
VBUS: JP1.2 (B); also elsewhere on the board
VMotor: C31.1, C32.1, C33.1, C34.1, PS1.6 (VIN); also elsewhere on the board

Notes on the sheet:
1MHz
VMotor to 5V Buck Regulator
Merge Buck and VBUS
.6V FB voltage
3.3V regulator
PFM at light load PG output

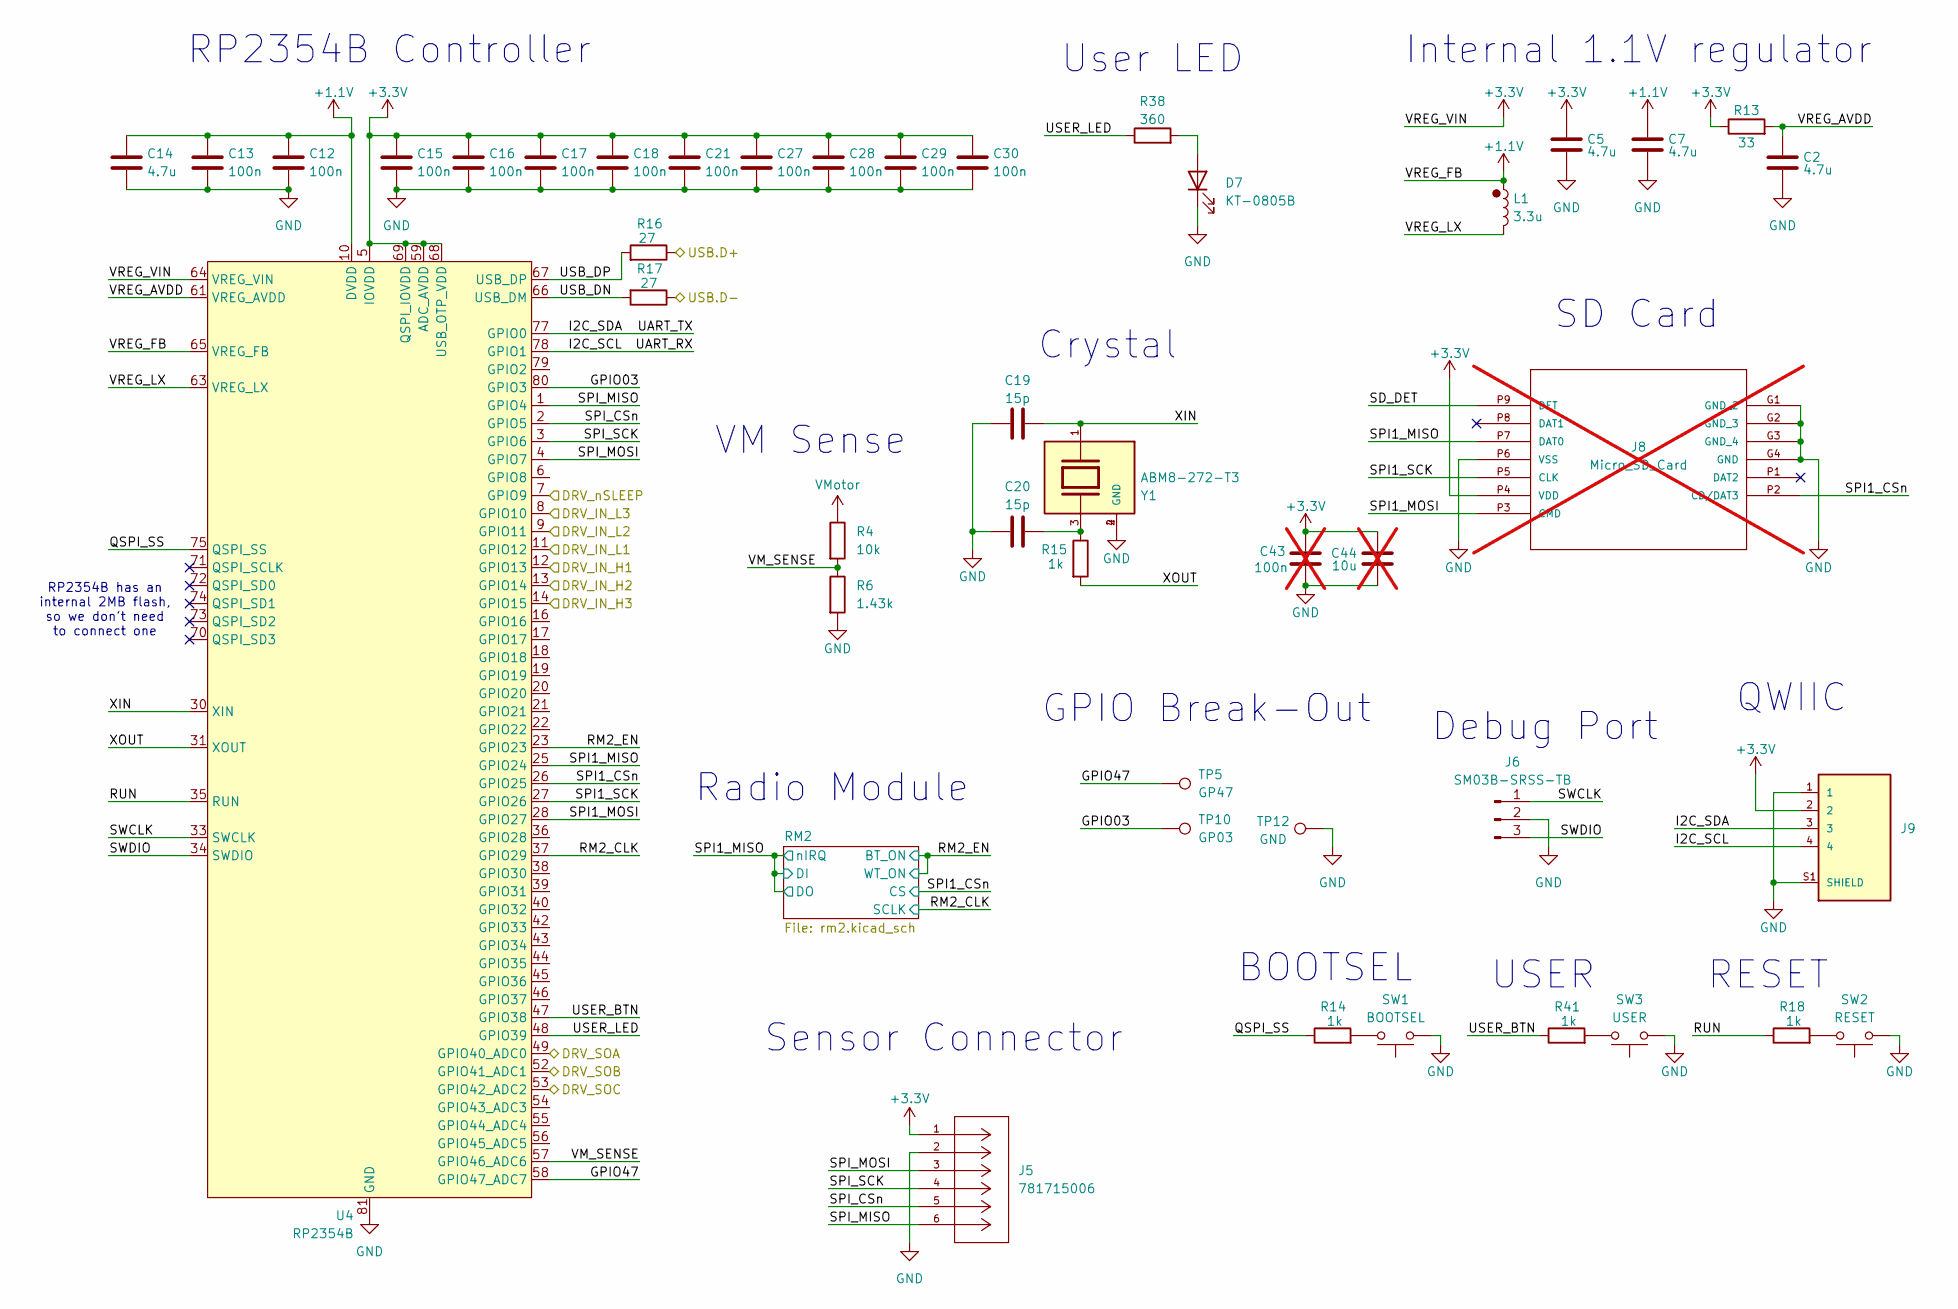
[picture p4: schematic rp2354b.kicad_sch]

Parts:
C2, C14: 4.7u; C_0402_1005Metric; MPN CL05A475MP5NRNC; LCSC C23733
C5, C7: 4.7u; C_0402_1005Metric_small_pads; MPN CL05A475MP5NRNC; LCSC C23733
C12, C13, C15, C16, C17, C18, C21, C27, C28, C29, C30: 100n; C_0402_1005Metric; MPN CL05B104KO5NNNC; LCSC C1525
C19, C20: 15p; C_0402_1005Metric; MPN 0402CG150J500NT; LCSC C1548
C43: 100n; C_0402_1005Metric; MPN CL05B104KO5NNNC; LCSC C1525; not fitted
C44: 10u; C_0603_1608Metric; MPN CL10A106KP8NNNC; LCSC C19702; not fitted
D7: KT-0805B; LED_0805_2012Metric; MPN KT-0805B; LCSC C2293
J5: 781715006; CONN06_781715006_MOL; MPN 781715006; LCSC C107412
J6: SM03B-SRSS-TB; JST_SH_SM03B-SRSS-TB_1x03-1MP_P1.00mm_Horizontal; MPN SM03B-SRSS-TB(LF)(SN); LCSC C160403
J8: Micro_SD_Card; 105162-0001_MOL; PARTREV 0; LCSC C3177046; not fitted
J9: SM04B-SRSS-TB_LF__SN_; JST_SM04B-SRSS-TB_LF__SN_; MPN SM04B-SRSS-TB(LF)(SN); LCSC C160404
L1: 3.3u; AOTAB201610S3R3101T; MPN AOTA-B201610S3R3-101-T; LCSC C42411119
R4: 10k; R_0402_1005Metric; MPN 0402WGF1002TCE; LCSC C25744
R6: 1.43k; R_0402_1005Metric; MPN RC0402FR-071K43L; LCSC C163483
R13: 33; R_0402_1005Metric; MPN 0402WGF330JTCE; LCSC C25105
R14, R15, R18, R41: 1k; R_0402_1005Metric; MPN 0402WGF1001TCE; LCSC C11702
R16, R17: 27; R_0402_1005Metric; MPN RC0402FR-0727RL; LCSC C138021
R38: 360; R_0402_1005Metric; MPN FRC0402F3600TS; LCSC C2930003
SW1: BOOTSEL; SW_SPST_B3U-1000P; MPN GT-TC032A-H015-L1; LCSC C843684
SW2: RESET; SW_SPST_B3U-1000P; MPN GT-TC032A-H015-L1; LCSC C843684
SW3: USER; SW_SPST_B3U-1000P; MPN GT-TC032A-H015-L1; LCSC C843684
TP5: GP47; TestPoint_Pad_D1.0mm
TP10: GP03; TestPoint_Pad_D1.0mm
TP12: GND; TestPoint_Pad_D1.0mm
U4: RP2354B; QFN-80-1EP_10x10mm_P0.4mm_EP3.4x3.4mm_ThermalVias; MPN RP2354B; LCSC C39843328
Y1: ABM8-272-T3; XTAL_ABM8-272-T3; PARTREV 07-29-20; LCSC C20625731

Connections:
+1.1V: C7.1, C12.1, C13.1, C14.1, L1.1, U4.10 (DVDD), U4.32 (DVDD), U4.51 (DVDD), U4.65 (VREG_FB)
+3.3V: C5.1, C15.1, C16.1, C17.1, C18.1, C21.1, C27.1, C28.1, C29.1, C30.1, C43.1, C44.1, J5.1, J8.P4 (VDD), J9.2, R13.1, U4.5 (IOVDD), U4.15 (IOVDD), U4.24 (IOVDD), U4.29 (IOVDD), U4.41 (IOVDD), U4.50 (IOVDD), U4.59 (ADC_AVDD), U4.60 (IOVDD), U4.64 (VREG_VIN), U4.68 (USB_OTP_VDD), U4.69 (QSPI_IOVDD), U4.76 (IOVDD); also elsewhere on the board
/DRV_IN_H1: U4.12 (GPIO13); also elsewhere on the board
/DRV_IN_H2: U4.13 (GPIO14); also elsewhere on the board
/DRV_IN_H3: U4.14 (GPIO15); also elsewhere on the board
/DRV_IN_L1: U4.11 (GPIO12); also elsewhere on the board
/DRV_IN_L2: U4.9 (GPIO11); also elsewhere on the board
/DRV_IN_L3: U4.8 (GPIO10); also elsewhere on the board
/DRV_SOA: U4.49 (GPIO40_ADC0); also elsewhere on the board
/DRV_SOB: U4.52 (GPIO41_ADC1); also elsewhere on the board
/DRV_SOC: U4.53 (GPIO42_ADC2); also elsewhere on the board
/DRV_nSLEEP: U4.7 (GPIO9); also elsewhere on the board
/RP2354B/GPIO03: TP10.1, U4.80 (GPIO3)
/RP2354B/GPIO47: TP5.1, U4.58 (GPIO47_ADC7)
/RP2354B/I2C_SCL: J9.4, U4.78 (GPIO1)
/RP2354B/I2C_SDA: J9.3, U4.77 (GPIO0)
/RP2354B/QSPI_SS: R14.1, U4.75 (QSPI_SS)
/RP2354B/RM2_CLK: U4.37 (GPIO29); also elsewhere on the board
/RP2354B/RM2_EN: U4.23 (GPIO23); also elsewhere on the board
/RP2354B/RUN: R18.1, U4.35 (RUN)
/RP2354B/SD_DET: J8.P9 (DET)
/RP2354B/SPI1_CSn: J8.P2 (CD/DAT3), U4.26 (GPIO25); also elsewhere on the board
/RP2354B/SPI1_MISO: J8.P7 (DAT0), U4.25 (GPIO24); also elsewhere on the board
/RP2354B/SPI1_MOSI: J8.P3 (CMD), U4.28 (GPIO27)
/RP2354B/SPI1_SCK: J8.P5 (CLK), U4.27 (GPIO26)
/RP2354B/SPI_CSn: J5.5, U4.2 (GPIO5)
/RP2354B/SPI_MISO: J5.6, U4.1 (GPIO4)
/RP2354B/SPI_MOSI: J5.3, U4.4 (GPIO7)
/RP2354B/SPI_SCK: J5.4, U4.3 (GPIO6)
/RP2354B/SWCLK: J6.1, U4.33 (SWCLK)
/RP2354B/SWDIO: J6.3, U4.34 (SWDIO)
/RP2354B/USB.D+: R16.1; also elsewhere on the board
/RP2354B/USB.D-: R17.1; also elsewhere on the board
/RP2354B/USB_DN: R17.2, U4.66 (USB_DM)
/RP2354B/USB_DP: R16.2, U4.67 (USB_DP)
/RP2354B/USER_BTN: R41.1, U4.47 (GPIO38)
/RP2354B/USER_LED: R38.1, U4.48 (GPIO39)
/RP2354B/VM_SENSE: R4.2, R6.1, U4.57 (GPIO46_ADC6)
/RP2354B/VREG_AVDD: C2.1, R13.2, U4.61 (VREG_AVDD)
/RP2354B/VREG_LX: L1.2, U4.63 (VREG_LX)
/RP2354B/XIN: C19.2, U4.30 (XIN), Y1.1
/RP2354B/XOUT: R15.2, U4.31 (XOUT)
GND: C2.2, C5.2, C7.2, C12.2, C13.2, C14.2, C15.2, C16.2, C17.2, C18.2, C19.1, C20.1, C21.2, C27.2, C28.2, C29.2, C30.2, C43.2, C44.2, D7.1 (K), J5.2, J6.2, J8.G1 (GND_2), J8.G2 (GND_3), J8.G3 (GND_4), J8.G4 (GND), J8.P6 (VSS), J9.1, J9.S1 (SHIELD), J9.S2 (SHIELD), R6.2, SW1.1, SW2.1, SW3.1, TP12.1, U4.62 (VREG_PGND), U4.81 (GND), Y1.2 (GND), Y1.4 (GND); also elsewhere on the board
unnamed: C20.2, R15.1, Y1.3
unnamed: D7.2 (A), R38.2
unnamed: R14.2, SW1.2
unnamed: R18.2, SW2.2
unnamed: R41.2, SW3.2
VMotor: R4.1; also elsewhere on the board

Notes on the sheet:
User LED
USER
Sensor Connector
VM Sense
Internal 1.1V regulator
BOOTSEL
Radio Module
QWIIC
Crystal
SD Card
RP2354B has an internal 2MB flash, so we don't need to connect one
GPIO Break-Out
RP2354B Controller
RESET
Debug Port

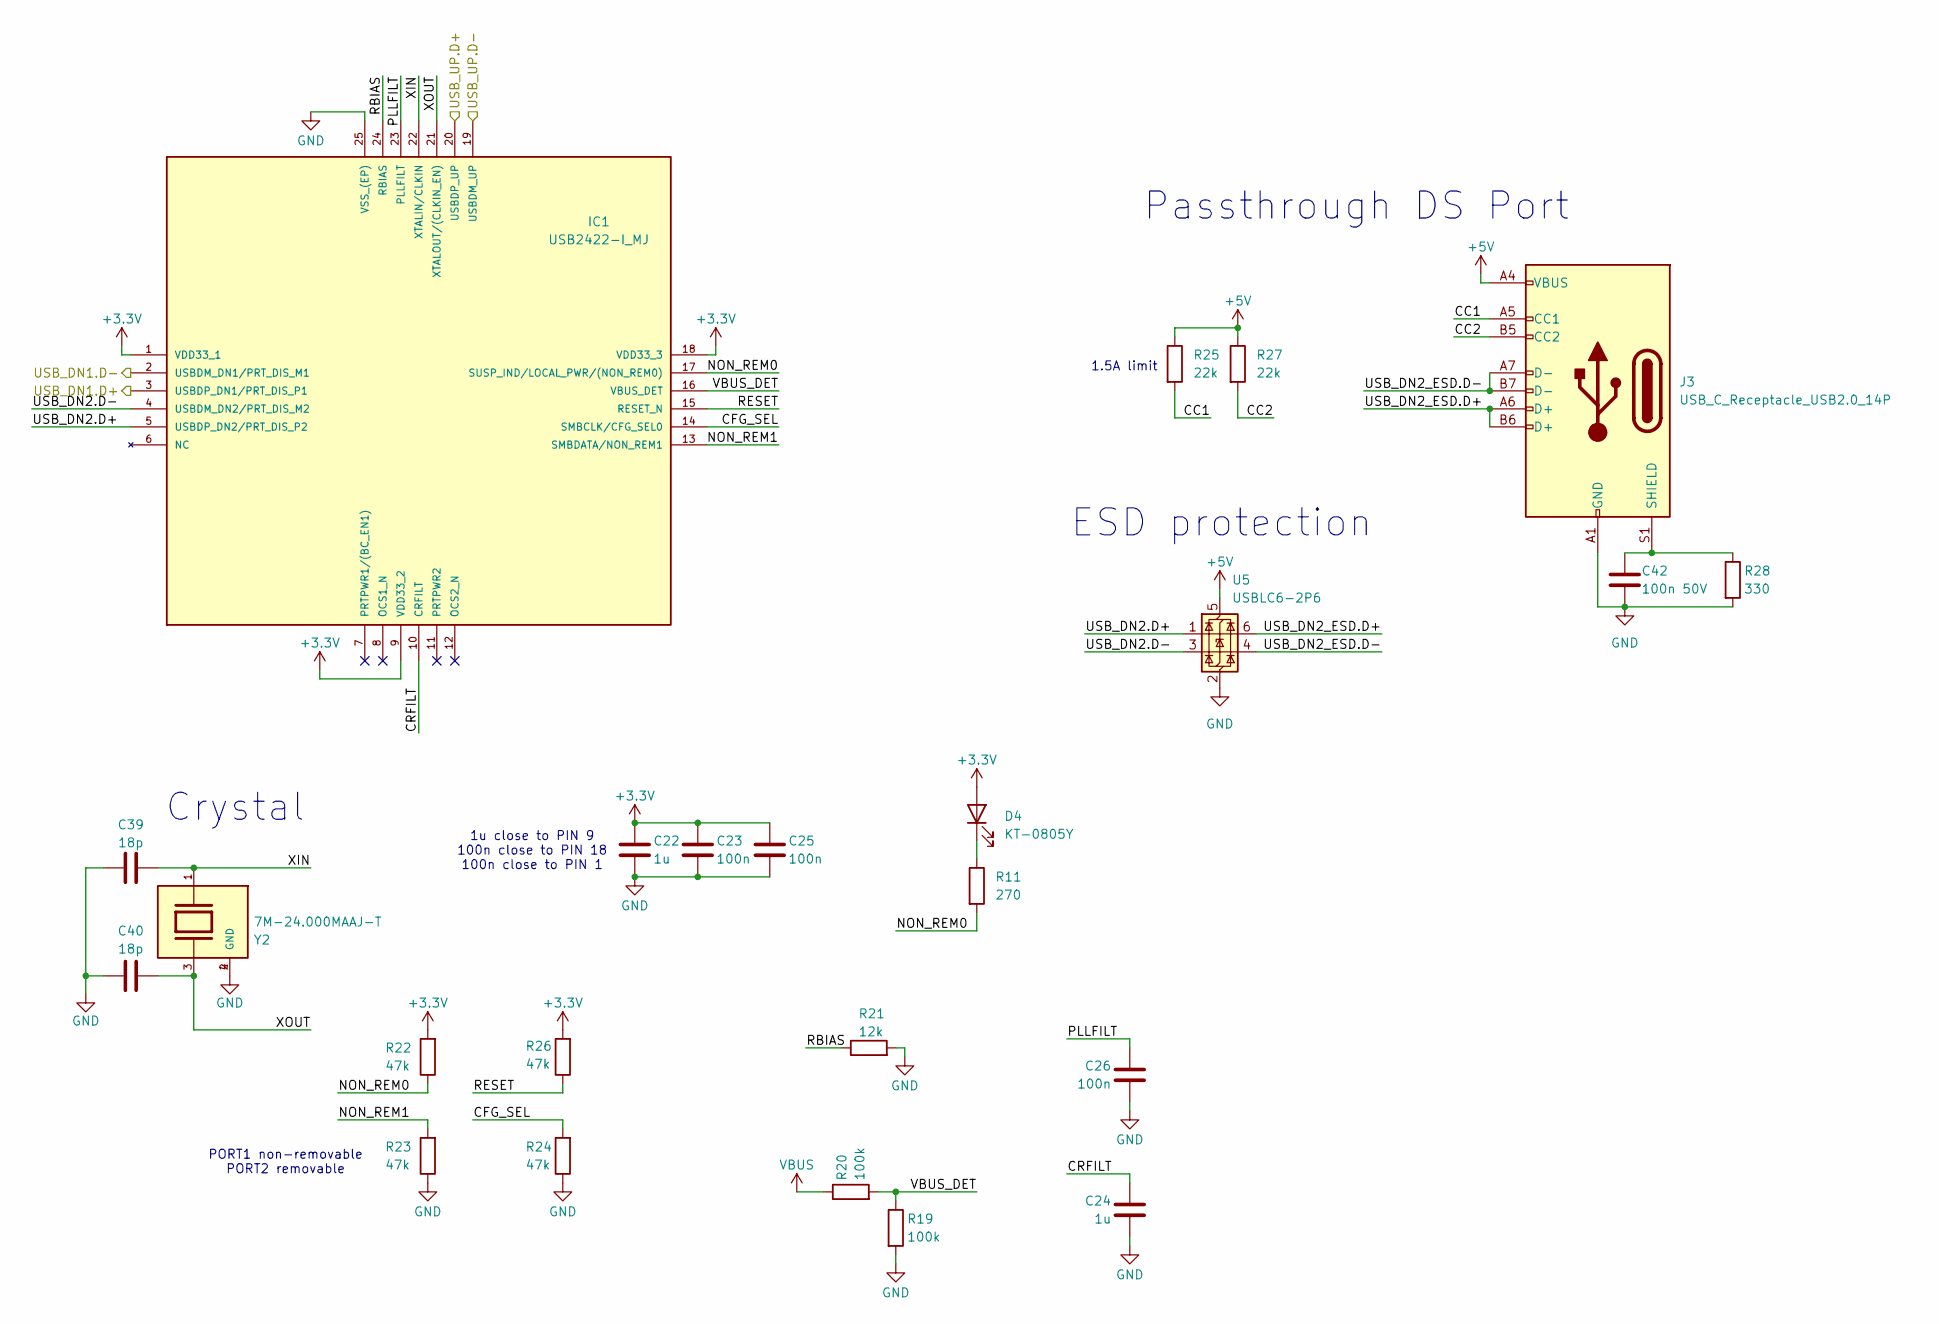
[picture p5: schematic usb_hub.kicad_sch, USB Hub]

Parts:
C22, C24: 1u; C_0402_1005Metric; MPN CL05A105KA5NQNC; LCSC C52923
C23, C25, C26: 100n; C_0402_1005Metric; MPN CL05B104KO5NNNC; LCSC C1525
C39, C40: 18p; C_0402_1005Metric; MPN 0402CG180J500NT; LCSC C1549
C42: 100n 50V; C_0402_1005Metric; MPN GRM155R71H104KE14D; LCSC C77020
D4: KT-0805Y; LED_0805_2012Metric; MPN KT-0805Y; LCSC C2296
IC1: USB2422-I_MJ; QFN50P400X400X100-25N; MOUSER_PART_NUMBER 579-USB2422-I/MJ
J3: USB_C_Receptacle_USB2.0_14P; USB_C_Receptacle_GCT_USB4105-xx-A_16P_TopMnt_Horizontal; MPN USB4105-GF-A-060; LCSC C3025063
R11: 270; R_0402_1005Metric; MPN RC0402FR-07270RL; LCSC C163474
R19, R20: 100k; R_0402_1005Metric; MPN 0402WGF1003TCE; LCSC C25741
R21: 12k; R_0402_1005Metric; MPN 0402WGF1202TCE; LCSC C25752
R22, R23, R24, R26: 47k; R_0402_1005Metric; MPN 0402WGF4702TCE; LCSC C25792
R25, R27: 22k; R_0402_1005Metric; MPN 0402WGF2202TCE; LCSC C25768
R28: 330; R_0402_1005Metric; MPN 0402WGF3300TCE; LCSC C25104
U5: USBLC6-2P6; SOT-666; MPN USBLC6-2P6; LCSC C2827693
Y2: 7M-24.000MAAJ-T; 7M24000MAAJT; PARTREV 07-29-20; LCSC C2450233

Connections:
+3.3V: C22.1, C23.1, C25.1, D4.2 (A), IC1.1 (VDD33_1), IC1.9 (VDD33_2), IC1.18 (VDD33_3), R22.2, R26.2; also elsewhere on the board
+5V: J3.A4 (VBUS), J3.A9 (VBUS), J3.B4 (VBUS), J3.B9 (VBUS), R25.1, R27.1, U5.5 (VBUS); also elsewhere on the board
/RP2354B/USB.D+: IC1.3 (USBDP_DN1/PRT_DIS_P1); also elsewhere on the board
/RP2354B/USB.D-: IC1.2 (USBDM_DN1/PRT_DIS_M1); also elsewhere on the board
/USB Hub/CC1: J3.A5 (CC1), R25.2
/USB Hub/CC2: J3.B5 (CC2), R27.2
/USB Hub/CFG_SEL: IC1.14 (SMBCLK/CFG_SEL0), R24.2
/USB Hub/CRFILT: C24.1, IC1.10 (CRFILT)
/USB Hub/NON_REM0: IC1.17 (SUSP_IND/LOCAL_PWR/(NON_REM0)), R11.2, R22.1
/USB Hub/NON_REM1: IC1.13 (SMBDATA/NON_REM1), R23.2
/USB Hub/PLLFILT: C26.1, IC1.23 (PLLFILT)
/USB Hub/RBIAS: IC1.24 (RBIAS), R21.1
/USB Hub/RESET: IC1.15 (RESET_N), R26.1
/USB Hub/USB_DN2.D+: IC1.5 (USBDP_DN2/PRT_DIS_P2), U5.1 (I/O1)
/USB Hub/USB_DN2.D-: IC1.4 (USBDM_DN2/PRT_DIS_M2), U5.3 (I/O2)
/USB Hub/USB_DN2_ESD.D+: J3.A6 (D+), J3.B6 (D+), U5.6 (I/O1)
/USB Hub/USB_DN2_ESD.D-: J3.A7 (D-), J3.B7 (D-), U5.4 (I/O2)
/USB Hub/VBUS_DET: IC1.16 (VBUS_DET), R19.1, R20.2
/USB Hub/XIN: C39.2, IC1.22 (XTALIN/CLKIN), Y2.1
/USB Hub/XOUT: C40.2, IC1.21 (XTALOUT/(CLKIN_EN)), Y2.3
/USB_D+: IC1.20 (USBDP_UP); also elsewhere on the board
/USB_D-: IC1.19 (USBDM_UP); also elsewhere on the board
GND: C22.2, C23.2, C24.2, C25.2, C26.2, C39.1, C40.1, C42.2, IC1.25 (VSS_(EP)), J3.A1 (GND), J3.A12 (GND), J3.B1 (GND), J3.B12 (GND), R19.2, R21.2, R23.1, R24.1, R28.2, U5.2 (GND), Y2.2 (GND), Y2.4 (GND); also elsewhere on the board
unnamed: D4.1 (K), R11.1
unnamed: C42.1, J3.S1 (SHIELD), R28.1
VBUS: R20.1; also elsewhere on the board

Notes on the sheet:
PORT1 non-removable PORT2 removable
1.5A limit
ESD protection
1u close to PIN 9 100n close to PIN 18 100n close to PIN 1
Passthrough DS Port
Crystal

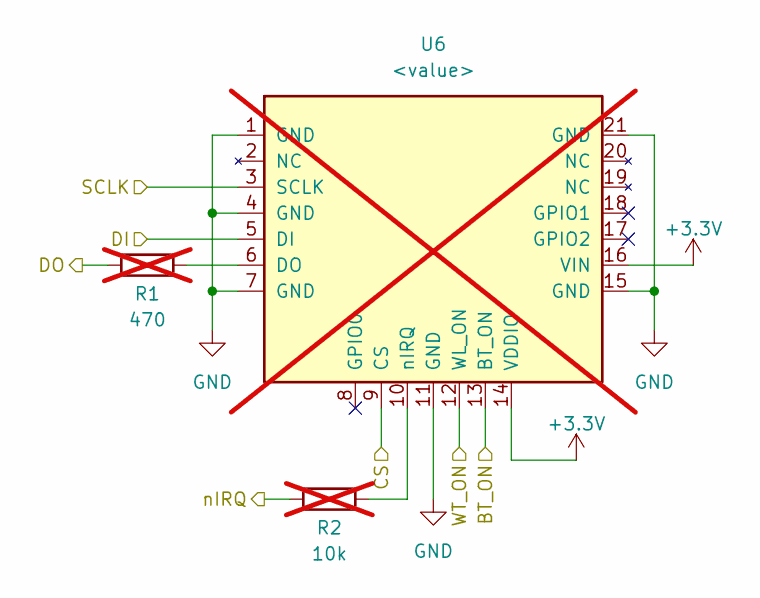
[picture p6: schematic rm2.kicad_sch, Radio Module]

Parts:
R1: 470; R_0402_1005Metric; MPN 0402WGF4700TCE; LCSC C25117; not fitted
R2: 10k; R_0402_1005Metric; MPN 0402WGF1002TCE; LCSC C25744; not fitted
U6: <value>; rpi_rmc20452t; not fitted

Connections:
+3.3V: U6.14 (VDDIO), U6.16 (VIN); also elsewhere on the board
/RP2354B/RM2_CLK: U6.3 (SCLK); also elsewhere on the board
/RP2354B/RM2_EN: U6.12 (WL_ON), U6.13 (BT_ON); also elsewhere on the board
/RP2354B/SPI1_CSn: U6.9 (CS); also elsewhere on the board
/RP2354B/SPI1_MISO: R1.2, R2.2, U6.5 (DI); also elsewhere on the board
GND: U6.1 (GND), U6.4 (GND), U6.7 (GND), U6.11 (GND), U6.15 (GND), U6.21 (GND); also elsewhere on the board
unnamed: R1.1, U6.6 (DO)
unnamed: R2.1, U6.10 (nIRQ)

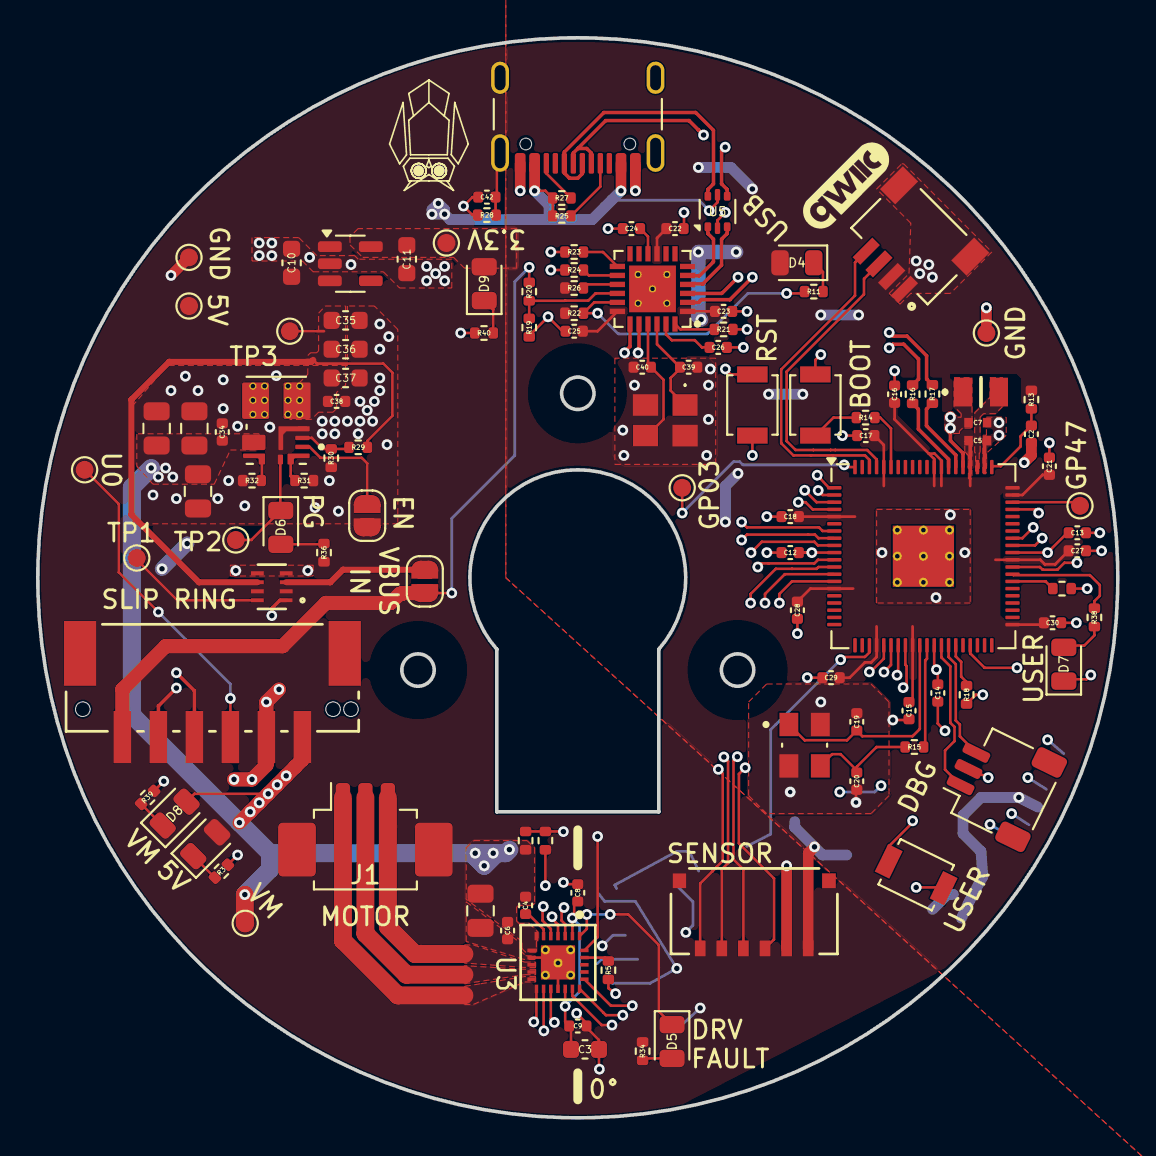
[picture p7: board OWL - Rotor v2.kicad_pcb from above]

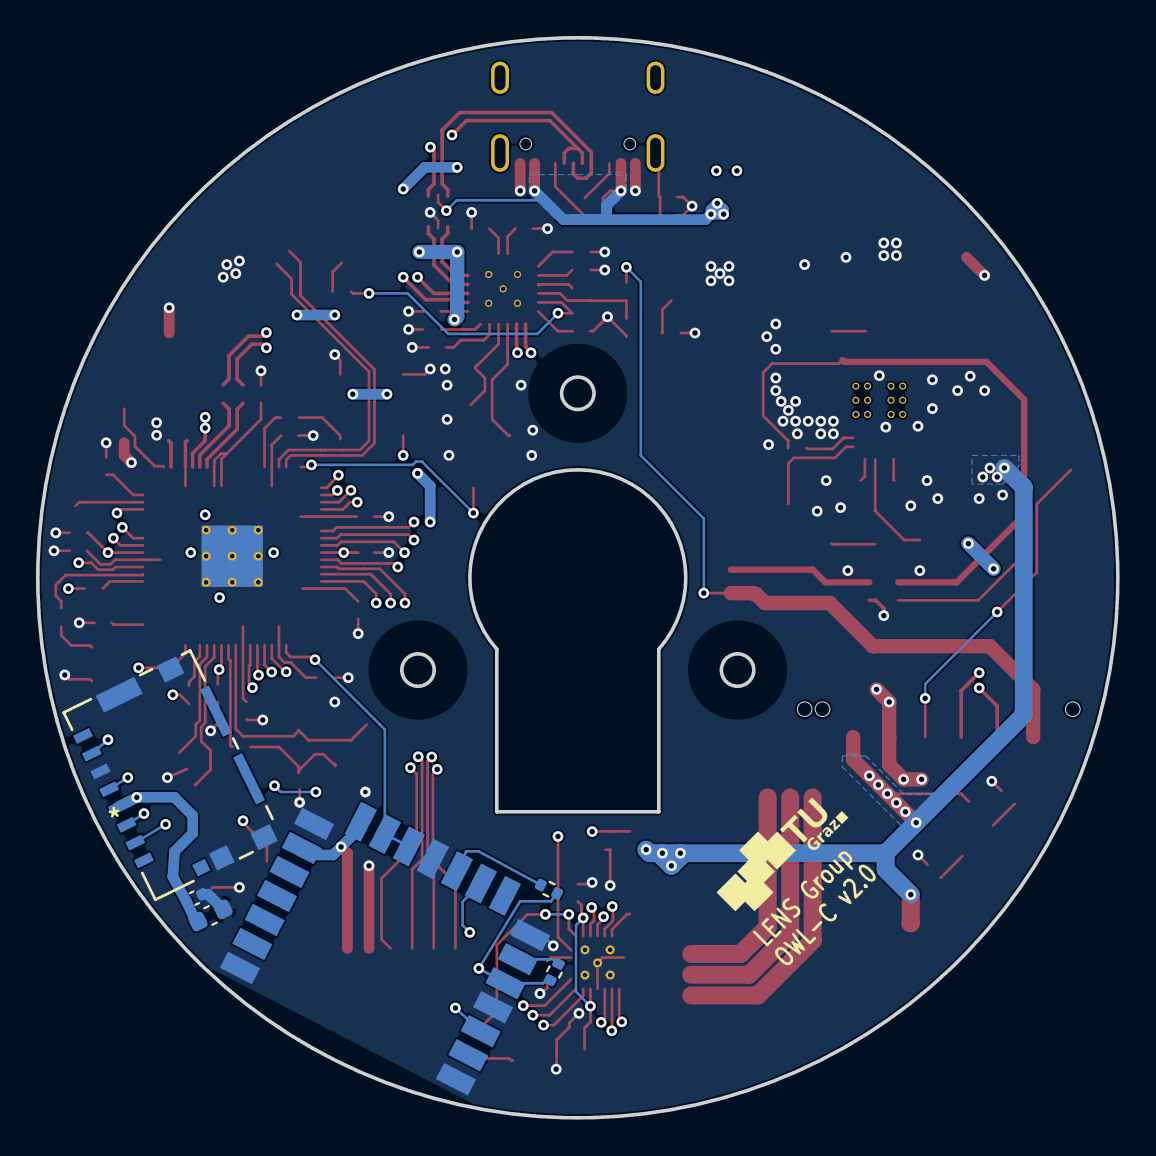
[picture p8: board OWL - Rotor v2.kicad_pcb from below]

Board: 4 copper layers, 60.0 x 60.0 mm, 117 parts (6 on the bottom side), 93 nets.

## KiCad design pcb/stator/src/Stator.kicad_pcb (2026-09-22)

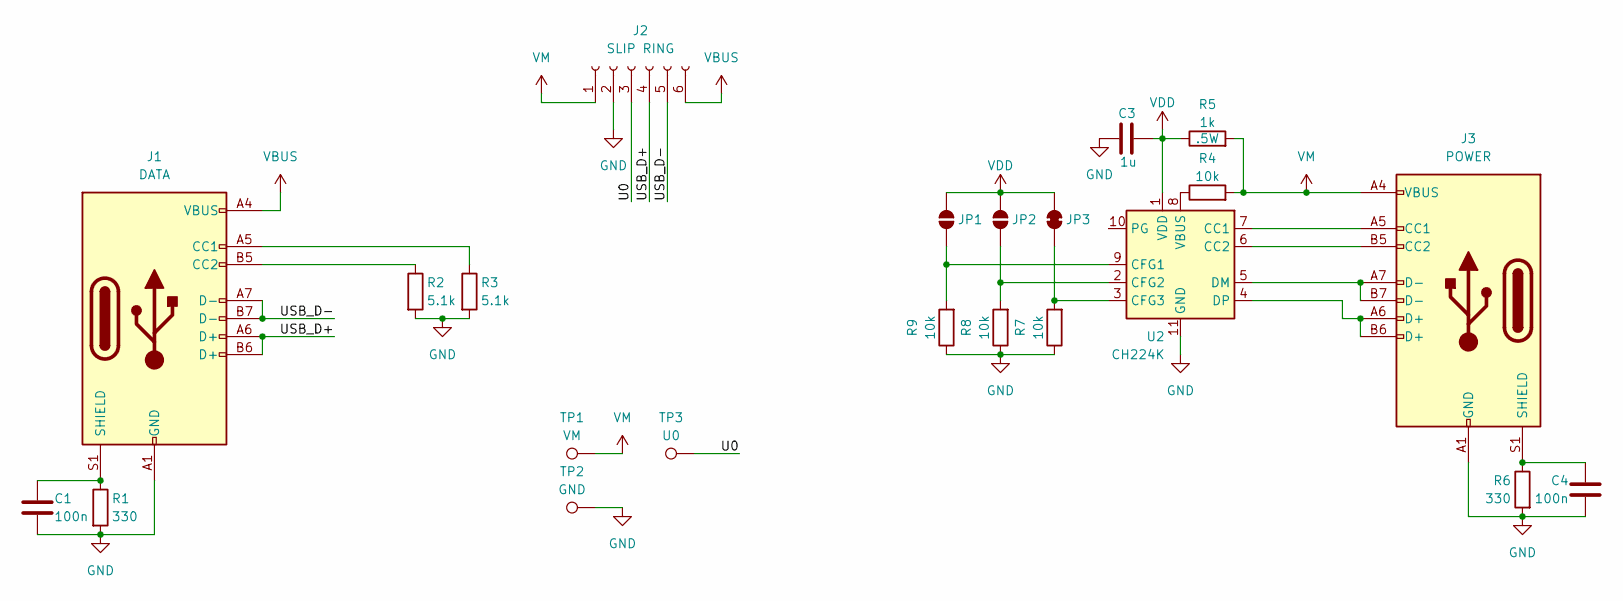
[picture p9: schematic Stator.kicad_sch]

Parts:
C1, C4: 100n; C_0402_1005Metric; MPN 0402F104M500NT; LCSC C1581
C3: 1u; C_0402_1005Metric; MPN CL05A105KA5NQNC; LCSC C52923
J1: DATA; USB_C_Receptacle_GCT_USB4110; MPN USB4110-GF-A; LCSC C5143397
J2: SLIP RING; CONN_BM06B-PASS-1_JST; MPN BM06B-PASS-TFT(LF)(SN); LCSC C265376
J3: POWER; USB_C_Receptacle_GCT_USB4110; MPN USB4110-GF-A; LCSC C5143397
JP1: C1; SolderJumper-2_P1.3mm_Open_RoundedPad1.0x1.5mm
JP2: C2; SolderJumper-2_P1.3mm_Open_RoundedPad1.0x1.5mm
JP3: C3; SolderJumper-2_P1.3mm_Bridged_RoundedPad1.0x1.5mm
R1, R6: 330; R_0402_1005Metric; MPN 0402WGF3300TCE; LCSC C25104
R2, R3: 5.1k; R_0402_1005Metric; MPN 0402WGF5101TCE; LCSC C25905
R4, R7, R8, R9: 10k; R_0402_1005Metric; MPN 0402WGF1002TCE; LCSC C25744
R5: 1k; R_0805_2012Metric; MPN AS05W2J0102T5E; LCSC C560481
TP1: VM; TestPoint_Pad_2.0x2.0mm
TP2: GND; TestPoint_Pad_2.0x2.0mm
TP3: U0; TestPoint_Pad_2.0x2.0mm
U2: CH224K; SSOP-10-1EP_3.9x4.9mm_P1mm_EP2.1x3.3mm; MPN CH224K; LCSC C970725

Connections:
/U0: J2.3, TP3.1
/USB_D+: J1.A6 (D+), J1.B6 (D+), J2.4
/USB_D-: J1.A7 (D-), J1.B7 (D-), J2.5
GND: C1.2, C3.2, C4.2, J1.A1 (GND), J1.A12 (GND), J1.B1 (GND), J1.B12 (GND), J2.2, J3.A1 (GND), J3.A12 (GND), J3.B1 (GND), J3.B12 (GND), R1.2, R2.2, R3.2, R6.2, R7.1, R8.1, R9.1, TP2.1, U2.11 (GND)
unnamed: J1.A5 (CC1), R3.1
unnamed: J1.B5 (CC2), R2.1
unnamed: C1.1, J1.S1 (SHIELD), R1.1
unnamed: J3.A5 (CC1), U2.7 (CC1)
unnamed: J3.B5 (CC2), U2.6 (CC2)
unnamed: C4.1, J3.S1 (SHIELD), R6.1
unnamed: JP1.1 (A), R9.2, U2.9 (CFG1)
unnamed: JP2.1 (A), R8.2, U2.2 (CFG2)
unnamed: JP3.1 (A), R7.2, U2.3 (CFG3)
unnamed: J3.A7 (D-), J3.B7 (D-), U2.5 (DM)
unnamed: J3.A6 (D+), J3.B6 (D+), U2.4 (DP)
unnamed: R4.1, U2.8 (VBUS)
VBUS: J1.A4 (VBUS), J1.A9 (VBUS), J1.B4 (VBUS), J1.B9 (VBUS), J2.6
VDD: C3.1, JP1.2 (B), JP2.2 (B), JP3.2 (B), R5.1, U2.1 (VDD)
VM: J2.1, J3.A4 (VBUS), J3.A9 (VBUS), J3.B4 (VBUS), J3.B9 (VBUS), R4.2, R5.2, TP1.1

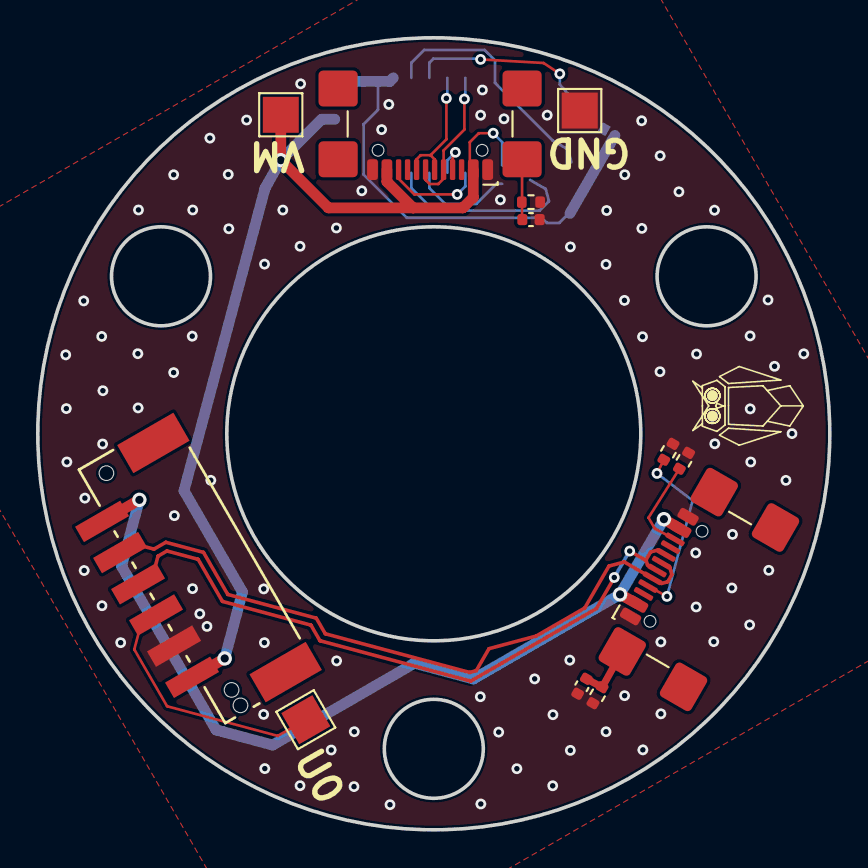
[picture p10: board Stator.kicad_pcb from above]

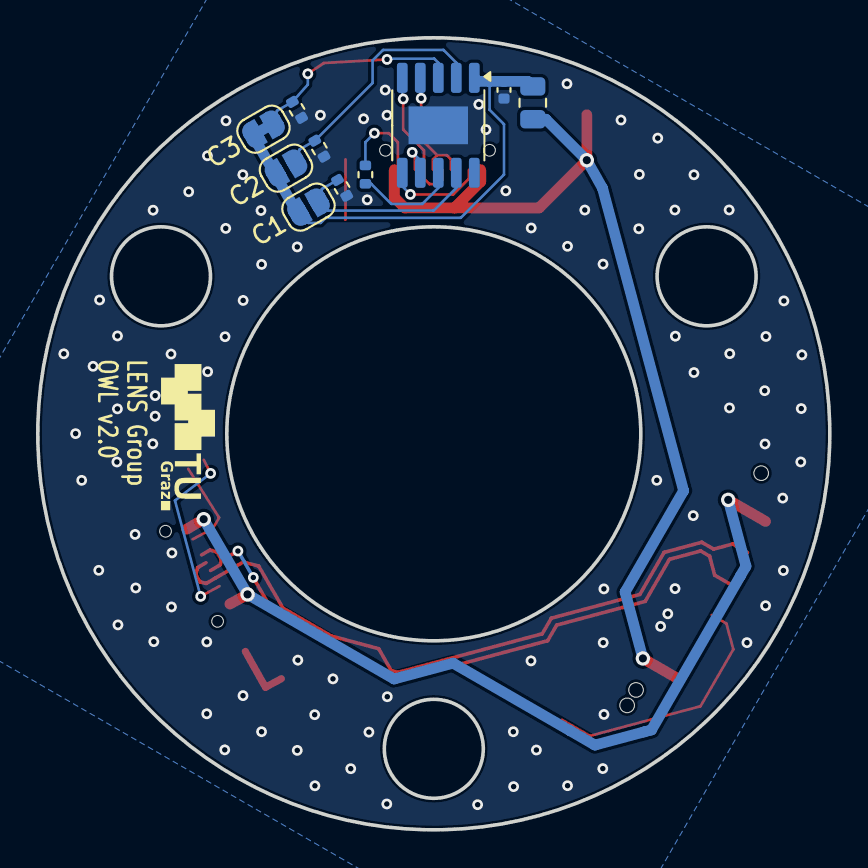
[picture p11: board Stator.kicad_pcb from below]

Board: 2 copper layers, 44.0 x 44.0 mm, 22 parts (10 on the bottom side), 19 nets.

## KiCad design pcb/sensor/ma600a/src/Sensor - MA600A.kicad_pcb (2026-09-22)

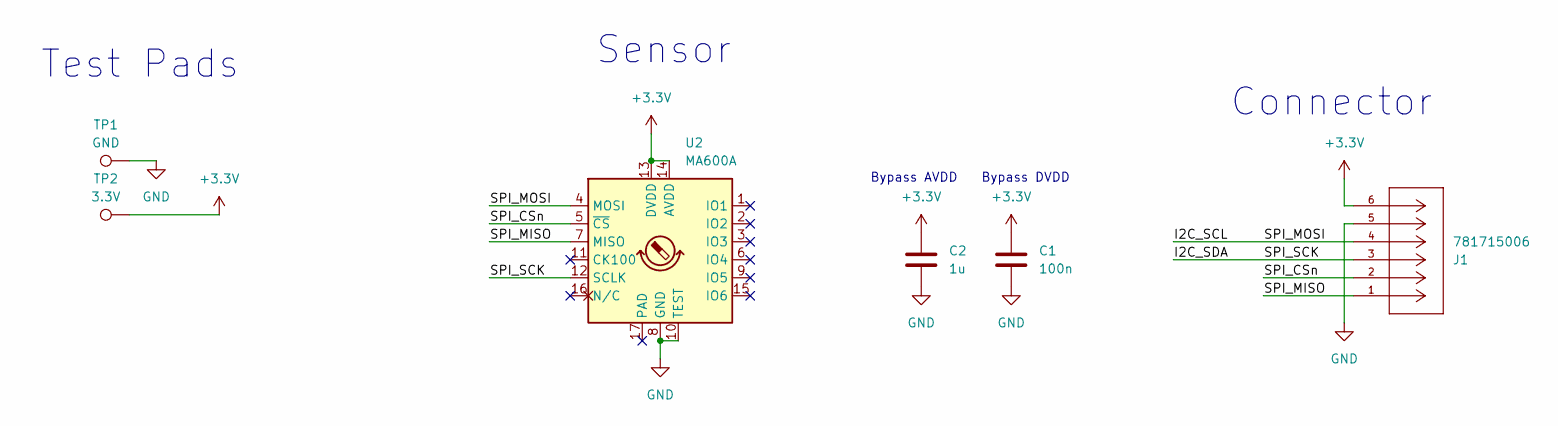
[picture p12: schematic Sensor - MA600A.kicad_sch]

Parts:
C1: 100n; C_0603_1608Metric; MPN CC0603KRX7R9BB104; LCSC C14663
C2: 1u; C_0603_1608Metric; MPN CL10A105KB8NNNC; LCSC C15849
J1: 781715006; CONN06_781715006_MOL; MPN 781715006; LCSC C107412
TP1: GND; TestPoint_Pad_D1.5mm
TP2: 3.3V; TestPoint_Pad_D1.5mm
U2: MA600A; QFN-16-1EP_3x3mm_P0.5mm_EP1.75x1.75mm; MPN MA600AGQE-0000-Z; LCSC C49240579

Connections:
+3.3V: C1.1, C2.1, J1.6, TP2.1, U2.13 (DVDD), U2.14 (AVDD)
/I2C_SCL: J1.4, U2.4 (MOSI)
/I2C_SDA: J1.3, U2.12 (SCLK)
/SPI_CSn: J1.2, U2.5 (~CS)
/SPI_MISO: J1.1, U2.7 (MISO)
GND: C1.2, C2.2, J1.5, TP1.1, U2.8 (GND), U2.10 (TEST)

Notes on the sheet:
Test Pads
Bypass DVDD
Connector
Bypass AVDD
Sensor



Board: 2 copper layers, 22.3 x 20.0 mm, 9 parts (2 on the bottom side), 6 nets.

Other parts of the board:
H1, H2, H3: MountingHole_1.8mm_M1.6

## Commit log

2026-09-21 Add assembly instructions and CAD readme
2026-09-22 Update assembly instructions: 9V supply, flashing, next steps
2026-09-22 Remove unused RP2040 sheet and old controller BOM
    [OWL - Rotor v2.csv, rp2040.kicad_sch]
2026-09-22 Add 3D-print exports and public Onshape link
    [OWL.3mf, Rotor - Board Spacers.step, Rotor - Payload Connector.step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]
2026-09-22 Add sensor board schematic PDF
2026-09-22 Move schematic PDFs out of src
2026-09-22 Add brim to 3D-print plate
    [OWL.3mf]
2026-09-22 Add manufacturer, MPN and LCSC part numbers to all boards
    Part numbers taken from the matched JLCPCB order BOMs. Also mark the RM2
    module (U6) and microSD socket (J8) as DNP, exclude test points from the
    BOM, use KT-0805B for D7, 100n 50V for C42 as built, and set ENIG as the
    surface finish.
    [OWL - Rotor v2.kicad_pcb, OWL - Rotor v2.kicad_sch, Sensor - MA600A.kicad_pcb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]
2026-09-22 Provide generic and JLCPCB production files outside src
    pcb/export-production.sh regenerates pcb/<board>/production/{generic,jlcpcb}
    with kicad-cli and the Fabrication Toolkit CLI. pcb/README.md documents the
    stackups and how to order.
    [bom.csv, controller-bom.csv, controller-positions.csv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]
2026-09-22 Add silkscreen outline and pin-1 marker to the USB hub (IC1)
    The footprint only had its pin-1 marker on Dwgs.User, which is not
    plotted, so the orientation was invisible on the board and in the
    JLCPCB placement preview.
    [OWL - Rotor v2.kicad_pcb]
2026-09-22 Add assembly photos to the instructions
    Photos are resized to 1600 px and stripped of EXIF metadata.
2026-09-22 Refill zones before exporting production files
    The generic files used the zone fills stored in the board while the
    Fabrication Toolkit refills them, so the two sets could differ when a
    board was saved without refilling. Both now come from one refilled copy.
2026-09-22 Lower the current of the green 5V and 3.3V LEDs
    R3 510 -> 1.43k and R40 150 -> 360, about 1.5 mA like the VM LED
    instead of 3-4 mA. Both values are already in the BOM.
    [OWL - Rotor v2.kicad_pcb, OWL - Rotor v2.kicad_sch, controller-bom.csv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]
2026-09-22 Make the sensor mounting holes drilled NPTH holes
    They were circles on Edge.Cuts, which got lost when the board was
    panelized. Three board-only 1.8 mm NPTH footprints (H1-H3) now put them
    in the drill file.
    [Sensor - MA600A.kicad_pcb]
2026-09-22 Route the second D+/D- pads of the stator data USB-C port
    J1 B6 and B7 were not connected, so the port only worked in one
    orientation.
    [Stator.kicad_pcb]
2026-09-22 Ship the controller VBUS jumper JP1 open
    With both USB VBUS and the regulator connected, the LM66200 keeps
    switching between the two nearly equal inputs and the 5V rail gets
    noisy. JP1 is now an open solder jumper, so the controller runs from
    the regulator only unless JP1 is bridged. The assembly instructions now
    flash with power connected and describe the LED check and JP1.
    [OWL - Rotor v2.kicad_pcb, power_supply.kicad_sch]
2026-09-22 Create a release with production and 3D-print files for each tag
2026-09-22 Point the build instructions to the release files
    Recommend the ready-to-print OWL.3mf and mention the STEP files as the
    alternative.
2026-09-22 Assemble the controller on the top side only
    Mark C43, C44 (bulk decoupling for the microSD socket and RM2 module)
    and R1, R2 (RM2 only) as DNP like J8 and U6, so the controller has no
    assembled bottom-side parts. They can still be hand-soldered.
    [OWL - Rotor v2.kicad_pcb, controller-bom.csv, controller-positions.csv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]
2026-09-23 Fix wording and typos in the assembly instructions
2026-09-23 Explain the startup calibration and the 0° position
2026-09-23 Stress checking part rotation in the assembly placement preview
    Also drop the sensor via change from the untested changes in the status.
2026-09-23 Add payload adapters, the tripod mount and the payload interface docs
    [dwm3001cdk.step, mocap.step, nrf52840dk.step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]
2026-10-20 Move the tripod mount to connector 4
    The mount is now a body with the 1/4" heat insert and the unmodified
    connector-4 base screwed on with three M1.6x8 screws. The base's spring
    arms flex in the plate plane, so it can't be fused onto a solid body; a
    0.4 mm relief keeps the arms off it. connector_4.py and build.py
    generate the parts.
2026-10-20 Move the payload adapters to connector 4
    Each holder is taken from its old adapter (plate and pegs removed,
    turned +10 deg so it keeps its pose relative to the motor screws) and
    fused onto the connector-4 adapter by build.py. nrf52840dk (-22 deg) and
    mocap (-3 deg) are turned further so they clear the alignment grooves.
    The 1/4" thread adapter's insert boss now stands on the mount face.
    The docs explain the twist lock and the design rules, and point to
    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
2026-10-20 Mark the connector-4 payload parts as untested
2026-10-20 Make the tripod mount body conical like the old mount
    The body narrows from the full base diameter to a 3.7 mm wall around
    the 1/4" insert, with the old mount's three grip flats between the
    screws, and prints upside down without supports. The base screws are
    now M1.6x6 so their pilot holes keep a 1.5 mm wall in the narrower body.
2026-10-20 Narrow the tripod mount body to a plain cone
    The body no longer flares out flush with the base: everything it
    supports (screws, arm relief) sits within R 12.4, and on the OWL the
    base only rests on three tubes. The 30 deg cone now runs straight to a
    31.6 mm top face.
2026-10-23 Rename connector 4 to payload connector version 2
    connector_4.py is now payload_connector.py. The docs call it version 2
    of the payload connector, incompatible with version 1. Geometry unchanged.
2026-10-27 Document the OWL rotor with payload connector version 2
    The rotor carries the version 2 connector base on a stand instead of the
    version 1 payload connector, screwed down with M1.6x20 socket head
    screws. Update the parts list, steps 22-23, the cad/ table and the
    version notes, and drop status and changelog notes from the READMEs.
    The step 22 photos showed version 1 and are no longer embedded.
    Claude-Session: https://claude.ai/code/session_019Lgt6r9TeJnacSymERCZ3A
2026-10-28 3D print files and docs image to new connector v2
2026-11-05 Add nRF7002dk mount
